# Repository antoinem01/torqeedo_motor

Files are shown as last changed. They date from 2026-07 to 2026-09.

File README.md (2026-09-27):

# Torqeedo motor

Arduino sketch that drives a Torqeedo motor over RS485, with a potentiometer for speed control and two safety switches (emergency stop and dead man switch).

## Documentation

- [Torqeedo 1103CL aansturing](docs/torqeedo-1103cl-aansturing.md)
- [Bench-test checklist](docs/bench-test-checklist.md)
- [IP68 & trillingsbestendige opbouw](docs/ip68-robuuste-opbouw.md)
- [Geïntegreerde PCB (alles op één print)](docs/pcb-geintegreerd.md)
- [KiCad-project: schema + printontwerp](hardware/kicad/README.md)

## Hardware

Components:

- Arduino Uno
- MAX485 TTL-RS485 module
- Potentiometer (speed control)
- Emergency stop button (normally closed)
- Dead man switch (normally open)
- Torqeedo Travel 1103 CL motor

Pins:

- `2` — RS485 TX (to MAX485 `DI`)
- `3` — RS485 RX (to MAX485 `RO`)
- `4` — RS485 DE (driver enable, to MAX485 `DE`+`RE`)
- `A0` — potentiometer wiper (speed control)
- `5` — emergency stop (normally closed button between pin and GND)
- `6` — dead man switch (normally open button between pin and GND)

### System diagram

Intended full setup, powered from the Torqeedo battery pack:

```mermaid
graph TD
    BAT["Torqeedo battery 29.6V<br/>(built-in BMS: overcharge/<br/>short-circuit/deep-discharge protection)"]
    SW["Main switch / pull-out plug"]
    FUSE1["Fuse ~40A<br/>(motor circuit)"]
    FUSE2["Fuse ~1A<br/>(logic circuit)"]
    MOTOR["Torqeedo Travel 1103 CL motor"]
    BUCK["DC-DC buck converter<br/>29.6V to 5-9V"]
    UNO["Arduino Uno"]
    TTL["MAX485 TTL-RS485 module"]
    POT["Potentiometer (A0)"]
    ESTOP["Emergency stop (pin 5)"]
    DMAN["Dead man switch (pin 6)"]

    BAT --> SW
    SW --> FUSE1 --> MOTOR
    SW --> FUSE2 --> BUCK --> UNO
    UNO -- "TX / RX / DE" --> TTL
    TTL -- "RS485 A/B twisted pair" --> MOTOR
    POT --> UNO
    ESTOP --> UNO
    DMAN --> UNO
    BAT -. "common ground" .- UNO
    BAT -. "common ground" .- TTL
```

Notes:

- Two **separate fuses**: a heavy one (~40A) for the motor circuit and a small one
  (~1A) for the logic circuit. A single shared fuse is risky — a motor current
  spike could take down the Arduino's power too.
- The Uno is powered from the same battery as the motor, via a DC-DC buck
  converter (29.6V → 5-9V), not from an independent power source.
- A main switch / pull-out plug in front of everything lets you fully de-energize
  the system, independent of the software emergency stop on pin 5.
- The battery, Uno and TTL module must share a **common ground** — easy to
  forget, but required for the RS485 signal reference to work reliably.

### RS485 wiring

A cheap MAX485 breakout module is used to convert the Arduino's UART signal to the
RS485 bus. On these modules DE and RE are usually tied together, so a single
Arduino pin can drive both:

| Arduino Uno | MAX485 module |
| --- | --- |
| `5V` | `VCC` |
| `GND` | `GND` |
| `2` (TX) | `DI` |
| `3` (RX) | `RO` |
| `4` (DE) | `DE` + `RE` (tied together) |
| — | `A` / `B` → to the Torqeedo RS485 bus |

Check the `A`/`B` polarity against the Torqeedo motor's connector documentation —
if the motor doesn't respond, try swapping `A` and `B`.

### Torqeedo model

Target motor: **Torqeedo Travel 1103 CL** (long-shaft).

**Status: validated against the real motor** (bench test, 2026-07-25). The sketch
was tested against an actual Travel 1103 CL powered from an adjustable DC supply
at 29 V, propeller in air (no load). The motor's controller drew ~0.06 A idle,
responded to throttle, and the propeller ran both **forward and reverse** as
commanded. The RS485 protocol (based on ArduPilot's `AP_Torqeedo`) works against
this model and firmware.

This validation was **no-load only**. The current bench rig is a breadboard
lash-up, not a robust install, and the on-water power topology (buck converter,
fuses, main switch) has not been built or tested yet. Keep testing carefully,
without load, before relying on it on the water.

### ⚠️ Safety

This sketch controls a real motor, potentially on a boat. Bugs, wiring mistakes,
or protocol misunderstandings can cause unexpected motor behavior. Always:

- Test on the bench, out of the water, with the propeller removed or the boat secured, before any on-water use.
- Verify the emergency stop and dead man switch actually cut power before trusting them.
- Use at your own risk — this project comes with **no warranty**, see [LICENSE](LICENSE).

## How it works

- Reads the potentiometer and drives the motor via an RS485 protocol with a CRC8 checksum.
- Speed is ramped up/down gradually (soft start/stop, max 10 units per 100 ms).
- The motor stops immediately on emergency stop or when the dead man switch is released.
- A watchdog timer (2 s) restarts the Arduino if the loop hangs.
- The number of errors/stops is tracked in EEPROM.

## Libraries

Only standard Arduino libraries are needed, no external dependencies:

- `SoftwareSerial`
- `EEPROM`
- `avr/wdt`

## Uploading

Open `Torqeedo_motor/Torqeedo_motor.ino` in the Arduino IDE (or use `arduino-cli`), select board **Arduino Uno**, and upload.

## Credits

The RS485 bus protocol (framing bytes `0xAC`/`0xAD`/`0xAE`, CRC8 checksum) is based on
[ArduPilot's `AP_Torqeedo` driver](https://github.com/ArduPilot/ardupilot/tree/master/libraries/AP_Torqeedo).
Many thanks to the ArduPilot project for documenting and implementing the Torqeedo bus protocol.

## License

GPLv3, see [LICENSE](LICENSE) — inherited from ArduPilot's GPLv3-licensed `AP_Torqeedo` driver, on which the protocol implementation is based.

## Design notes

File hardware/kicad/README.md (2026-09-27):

# KiCad-project — geïntegreerde besturingsprint

Schema **en** printontwerp voor de geïntegreerde besturingsprint uit
[`../../docs/pcb-geintegreerd.md`](../../docs/pcb-geintegreerd.md).

## Bestanden

| Bestand | Inhoud |
|---|---|
| `torqeedo_pcb.kicad_pro` | projectbestand — **open dit in KiCad** |
| `torqeedo_pcb.kicad_sch` | schema (netlist, footprints toegewezen) |
| `torqeedo_pcb.kicad_pcb` | **printontwerp: geplaatst, gerouteerd, massavlakken** |
| `fab/` | Gerbers + boorbestanden (`*-gerbers.zip`), BOM, plaatsingsbestand |
| `pcb-top.png` / `pcb-bottom.png` | 3D-weergave van boven- en onderkant |

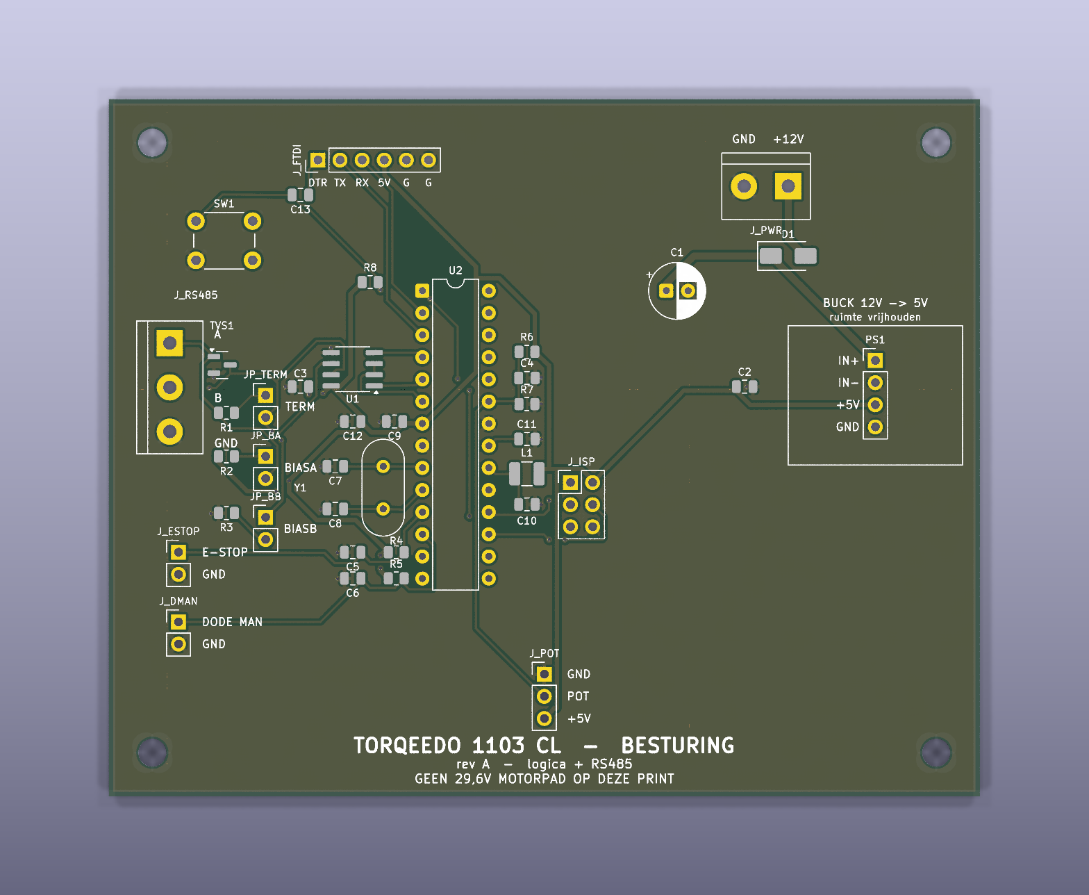
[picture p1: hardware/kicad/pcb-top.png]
Bovenkant


De symbolen zijn **in het schema ingebed**; de footprints komen uit de
**standaard KiCad-bibliotheken** (KiCad 9). Geen externe libraries nodig.

## De print

| | |
|---|---|
| Formaat | **100 × 80 mm**, 2 lagen, 1,6 mm |
| Montage | 4× **M3** (⌀3,2 mm) op 5 mm van elke hoek |
| Koperlagen | **F.Cu** = signalen, **B.Cu** = doorlopend **massavlak** (92,8 % dicht, één eiland) |
| Baanbreedtes | 0,25 mm signaal · 0,50 mm +5 V/GND · 0,80 mm +12 V |
| Via's | 0,7 mm pad / 0,35 mm boring — 32 stuks, waarvan 15 stitching-via's naar het massavlak |
| Clearance | 0,25 mm (netclasses `Default` / `Power` / `HV` staan in het projectbestand) |

De onderlaag is bewust bijna onaangeroerd gelaten: alleen een handvol korte
oversteekjes, zodat het massavlak een **aaneengesloten retourpad** blijft.

## Indeling

```
 ┌──────────────────────────────────────────────────────────┐
 │  SW1  C13   J_FTDI                          J_PWR  D1    │  ← 12 V in, ompoling
 │                                        C1        ┌─────┐ │
 │ J_RS485  TVS1  JP_*   U1      U2    R6/C4/R7  C2 │BUCK │ │  ← 12 V→5 V module
 │   A/B/G  R1-R3        MAX485  ATmega  C11        │PS1  │ │     (ruimte vrij)
 │                       C3      328P    L1/C10     └─────┘ │
 │                   C7 Y1 C8            J_ISP              │
 │ J_ESTOP    C5/C6  R4/R5                                  │
 │ J_DMAN                     J_POT                         │
 │            TORQEEDO 1103 CL - BESTURING  rev A           │
 └──────────────────────────────────────────────────────────┘
```

De plaatsing volgt de aandachtspunten uit
[`pcb-geintegreerd.md` §11](../../docs/pcb-geintegreerd.md):

- **Kristal Y1 staat pal tegen pin 9/10** van de ATmega — XTAL1 is 9,1 mm en
  XTAL2 10,0 mm lang, beide zonder via, met C7/C8 er direct naast.
- **Ontkoppeling tegen de voedingspinnen:** C9 bij VCC (pin 7), C3 bij MAX485
  pin 8, L1+C10 (AVCC-filter) direct bij pin 20, C11 bij AREF.
- **Analoge tak kort en ver van de buck:** C4/R6/R7 staan tegen pin 23; de
  A0-baan loopt op **40,9 mm** van de buck-module en 18,3 mm van het
  12 V-koper.
- **RS485 bij de connector:** terminatie (R1/JP_TERM), bias (R2/R3/JP_BA/JP_BB)
  en TVS1 staan tussen U1 en J_RS485; A en B lopen als paar.
- **Voedingsscheiding:** J_PWR, D1, C1 en de buck zitten samen in de
  rechterbovenhoek, gescheiden van de 5 V-logica en de A0-lijn.
- **Veldbedrading** (RS485, potmeter, noodstop, dode man) zit aan de linker- en
  onderrand; **programmeerheaders** (J_FTDI, J_ISP) liggen vrij bereikbaar.

Op de silkscreen staan de aansluitingen benoemd (`+12V`/`GND`, `A`/`B`/`GND`,
`POT`, `E-STOP`, `DODE MAN`, `IN+`/`IN-`/`+5V`/`GND`, `DTR TX RX 5V G G`), plus
het gereserveerde vlak voor de buck-module.

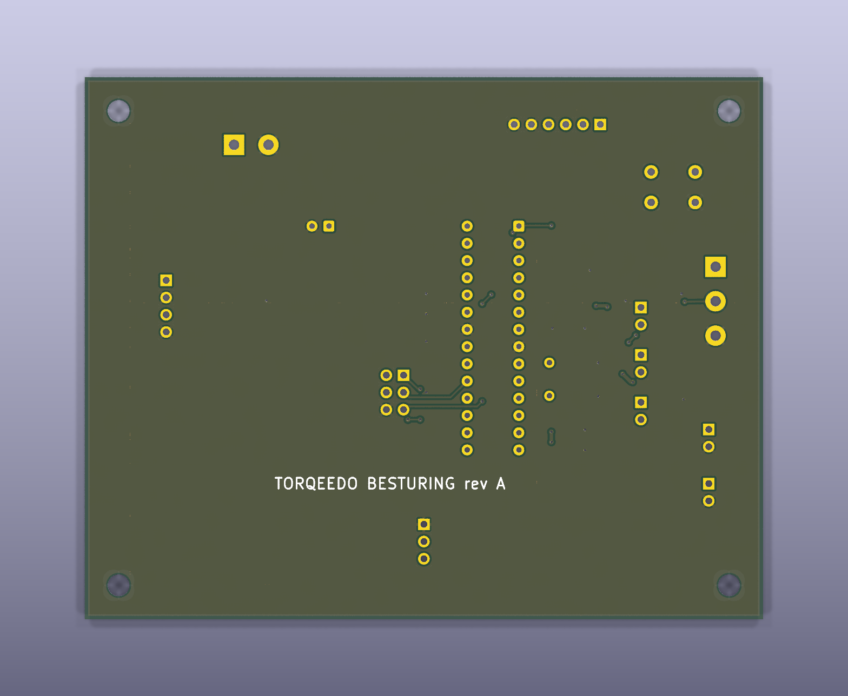
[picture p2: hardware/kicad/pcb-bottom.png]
Onderkant — doorlopend massavlak


## Verificatiestatus

Gecontroleerd met KiCad 9.0.2:

- **DRC: 0 overtredingen, 0 onverbonden items** (inclusief silkscreen- en
  afbakeningsregels).
- **Netlist print = netlist schema:** alle **114 pad-net-verbindingen** en 39
  componenten komen exact overeen; geen footprint-afwijkingen.
- Alle silkscreen-tekst valt binnen de bordrand.

> Dit is een **ontwerp-verificatie, geen gebouwde print.** Zie hieronder wat je
> vóór bestellen zelf moet nakijken.

## Nakijken vóór je bestelt

1. **PS1 buck-module** — de 1×4 header gaat uit van de padvolgorde
   **IN+ / IN− / OUT+ / OUT−**. Leg dit naast de pinout van *jouw* module en pas
   de footprint of de bedrading aan als die anders is. Het silkscreen-kader
   (20 × 16 mm) is de ruimte die de module krijgt — controleer of hij past.
2. **TVS1 SM712** — aangenomen SOT-23-pinout is pin 1 = A, 2 = GND, 3 = B.
   Controleer tegen het datasheet (optioneel onderdeel, dus laag risico).
3. **D1** — kathode (band) hoort aan de `+12V_PROT`-kant; zo is hij bedraad,
   controleer de silk-oriëntatie.
4. **C2/C12 (10 µF)** staan als keramisch 0805. Wil je elco's, wijs dan
   `CP_Radial` toe en let op polariteit.
5. **J_FTDI VCC** — laat los als de print al via de buck gevoed wordt
   (zie [`pcb-geintegreerd.md` §5](../../docs/pcb-geintegreerd.md)).

## Fabricagebestanden opnieuw maken

```sh
kicad-cli pcb export gerbers --no-protel-ext \
  --layers F.Cu,B.Cu,F.Mask,B.Mask,F.Silkscreen,B.Silkscreen,F.Paste,Edge.Cuts \
  -o fab/ torqeedo_pcb.kicad_pcb
kicad-cli pcb export drill --format excellon --excellon-separate-th -o fab/ torqeedo_pcb.kicad_pcb
kicad-cli pcb export pos --format csv --units mm --side both -o fab/torqeedo_pcb-pos.csv torqeedo_pcb.kicad_pcb
kicad-cli pcb drc --severity-error --severity-warning torqeedo_pcb.kicad_pcb
```

`fab/torqeedo_pcb-gerbers.zip` is wat je bij een fabrikant (JLCPCB, Aisler,
Eurocircuits) uploadt. Standaard 2-laags 1,6 mm proces; de kleinste maten op de
print (0,25 mm baan, 0,35 mm boring) zitten ruim binnen wat iedereen aankan.

## Bekende oneffenheid

De referenties `J_PWR`, `J_POT`, `JP_BA`, … eindigen niet op een cijfer. KiCad
ziet zulke namen als **niet-geannoteerd** en meldt dat bij het openen van het
schema; in de BOM verschijnen ze als `J_PWR?`. Dat is **cosmetisch** — netlist,
print en fabricagebestanden zijn correct (de print gebruikt de namen zonder
`?`). Wil je het weg hebben, hernoem dan in het schema naar bijvoorbeeld
`J_PWR1`; dan moeten de verwijzingen in `docs/pcb-geintegreerd.md` mee.

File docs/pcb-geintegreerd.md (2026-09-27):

# Geïntegreerde PCB (alles op één print)

Schema-ontwerp voor **één print waarop alles samenkomt**: een kale
**ATmega328P** (geen Arduino-module), de **MAX485**, de **12 V→5 V-voeding**,
de connectoren en de bus-beveiliging. Dezelfde sketch (`Torqeedo_motor.ino`)
draait ongewijzigd op de losse ATmega — de Nano is enkel vervangen door de chip
zelf plus een kristal, reset-circuit en een programmeer-header.

Een **KiCad-project** met zowel het schema als het **uitgewerkte printontwerp**
staat in [`../hardware/kicad/`](../hardware/kicad/) (open `torqeedo_pcb.kicad_pro`).
De print is 100 × 80 mm, 2-laags, volledig gerouteerd met een doorlopend
massavlak op de onderlaag, en DRC-schoon; `hardware/kicad/fab/` bevat de
Gerbers om hem te laten maken. De [hardware-README](../hardware/kicad/README.md)
beschrijft de indeling en wat je vóór bestellen nog moet nakijken.

Dit document geeft de **elektrische** kant (blokschema, connectielijst,
onderdelenlijst). De waterdichte/trillingsbestendige opbouw staat in
[`ip68-robuuste-opbouw.md`](ip68-robuuste-opbouw.md); de pinout en het protocol
in [`torqeedo-1103cl-aansturing.md`](torqeedo-1103cl-aansturing.md); de
voedingstopologie (accu, zekeringen, hoofdschakelaar) in de
[`README`](../README.md).

> ⚠️ Deze print is de **logica + RS485** ("brain"). Het **zware motorpad
> (~40 A, 29,6 V)** en de **40 A-zekering** horen er **niet** op — die lopen
> los langs de print, precies zoals de twee-zekeringen-opzet in de README.
> Op deze print komt alleen de **gelogde ~1 A tak** binnen.

---

## 1. Voeding: 12 V → 5 V

De print wordt gevoed met **12 V** en maakt daar met een buck **5,0 V** van.
Die 5 V voedt de ATmega, de MAX485, de potmeter en de pull-ups.

De 12 V komt van een **12 V-tak** — in de praktijk een 29,6 V→12 V-omvormer
bovenstrooms, of een aparte 12 V-accu aan boord. Alleen de gelogde ~1 A tak
(met de ~1 A-zekering uit de README) komt hier binnen; het 29,6 V motorpad
blijft er volledig van gescheiden.

**Buck als module op de print (aanbevolen).** Monteer een kant-en-klare
12 V→5 V buck-module op headers/pads op dezelfde print. Het blijft één PCB waar
alles samenkomt, maar je vermijdt het lastigste stuk voor een eerste eigen
ontwerp: de layout van een schakelende regelaar (inductor, feedback, ground
return). *Optie:* volledig integreren met een buck-IC (MP2307/MP1584/LM2596 +
inductor + dioden/caps) als je vertrouwd bent met switching-layout.

```mermaid
graph LR
    subgraph OFFBOARD["Buiten de print"]
        FUSE["Zekering ~1A"]
        POT["Potmeter 10k"]
        ESTOP["Noodstop (NC)"]
        DMAN["Dode man (NO)"]
        MOTOR["Torqeedo RS485-bus"]
    end

    subgraph PCB["Geïntegreerde PCB"]
        D1["D1 Schottky<br/>ompoolbeveiliging"]
        BUCK["Buck 12V → 5,0V"]
        MCU["ATmega328P<br/>+ 16MHz kristal<br/>+ reset + ISP/FTDI"]
        MAX["MAX485 (SO-8)<br/>+ terminatie/bias/TVS"]
    end

    FUSE -->|+12V| D1 --> BUCK -->|"+5V"| MCU
    MCU -->|"PD2/PD3/PD4"| MAX
    MCU -->|"+5V"| MAX
    POT -->|PC0/A0| MCU
    ESTOP -->|PD5/D5| MCU
    DMAN -->|PD6/D6| MCU
    MAX -->|"A / B / GND"| MOTOR
```

---

## 2. ATmega328P (U2) — kern

De kale chip vervangt de Nano. Voor betrouwbare SoftwareSerial (19200 baud) is
een **extern 16 MHz-kristal** nodig; de interne 8 MHz-RC-oscillator is te
onnauwkeurig voor stabiele seriële timing. Draai de **Arduino Uno-bootloader**
en dezelfde sketch — de code is 1-op-1 overdraagbaar.

Benodigd rond de chip:

- **Y1 16 MHz-kristal** + **C7/C8 (22 pF)** naar GND, vlak bij XTAL1/XTAL2
  (pin 9/10).
- **Reset:** R8 (10 kΩ) van RESET (pin 1) naar +5 V; optionele reset-knop naar
  GND; C13 (100 nF) van de FTDI-DTR-lijn naar RESET voor auto-reset bij uploaden.
- **Ontkoppeling:** C9 (100 nF) bij VCC (pin 7), C12 (10 µF) bulk vlakbij.
- **Schone ADC-voeding** (belangrijk voor een stabiele pot-meting): **L1
  (10 µH of ferriet)** tussen +5 V en **AVCC (pin 20)**, met **C10 (100 nF)**
  van AVCC naar AGND. **AREF (pin 21)** via **C11 (100 nF)** naar GND (interne
  AVcc-referentie; géén externe ref aansluiten). **AGND (pin 22)** naar GND.
- **J_ISP (2×3):** bootloader branden / direct programmeren (MISO/MOSI/SCK/
  RESET/VCC/GND).
- **J_FTDI (1×6):** uploaden en Serial-debug via een externe USB-serial-adapter
  (§5).

---

## 3. Pintoewijzing (sketch → fysieke ATmega-pin)

De Arduino-pinnamen uit `Torqeedo_motor.ino` mappen zo op de DIP-28/TQFP-32:

| Sketch | Arduino | ATmega-pin (DIP-28) | Poort | Gaat naar |
|---|---|---|---|---|
| `RS485_TX` | D2 | 4 | PD2 | MAX485 **DI** (pin 4) |
| `RS485_RX` | D3 | 5 | PD3 | MAX485 **RO** (pin 1) |
| `RS485_DE` | D4 | 6 | PD4 | MAX485 **DE**+**RE** (pin 3+2) |
| `POT_PIN` | A0 | 23 | PC0 | potmeter-loper (§7) |
| `NOODSTOP_PIN` | D5 | 11 | PD5 | noodstop (§8) |
| `DODE_MAN_PIN` | D6 | 12 | PD6 | dode man (§8) |
| Serial TX | D1 | 3 | PD1 | J_FTDI RXI (debug/upload) |
| Serial RX | D0 | 2 | PD0 | J_FTDI TXO (debug/upload) |

Voeding/klok/reset: VCC pin 7, GND pin 8, AVCC pin 20, AGND pin 22, AREF pin 21,
XTAL1/2 pin 9/10, RESET pin 1.

---

## 4. MAX485 (U1, SO-8)

Standaard MAX485-pinout. **DE en RE aan elkaar** en samen naar `D4` (PD4), zodat
één pin zenden/ontvangen omschakelt.

| MAX485-pin | Naam | Verbinding |
|---|---|---|
| 1 | RO | ATmega PD3 (pin 5) |
| 2 | RE̅ | samen met pin 3 → ATmega PD4 (pin 6) |
| 3 | DE | samen met pin 2 → ATmega PD4 (pin 6) |
| 4 | DI | ATmega PD2 (pin 4) |
| 5 | GND | GND |
| 6 | A | bus **A** → J_RS485 |
| 7 | B | bus **B** → J_RS485 |
| 8 | VCC | +5 V (100 nF ontkoppeling naar GND, dicht bij pin 8) |

---

## 5. Programmeren & debug (J_FTDI, 1×6)

Brand eenmalig de bootloader via **J_ISP** (met een USBasp/Arduino-as-ISP).
Daarna upload je net als een Arduino Pro Mini via een **USB-serial-adapter** op
J_FTDI, en dient dezelfde header voor de Serial-debugregels uit de sketch.

| J_FTDI-pin | Functie | Verbinding |
|---|---|---|
| DTR | auto-reset | via C13 (100 nF) → RESET (pin 1) |
| RXI | adapter **ontvangt** | → ATmega **TX** = PD1 (pin 3) |
| TXO | adapter **zendt** | → ATmega **RX** = PD0 (pin 2) |
| VCC | 5 V | zie noot |
| CTS | — | GND |
| GND | massa | GND |

> **RX/TX kruisen:** de adapter-RX gaat naar de chip-TX en andersom — de klassieke
> valkuil. **VCC-noot:** laat J_FTDI VCC **los** als de print al door de buck
> (12 V) gevoed wordt, om twee bronnen op +5 V te vermijden. Voor kaal
> bench-programmeren zonder 12 V mag je juist wél via J_FTDI VCC voeden.

---

## 6. Connectielijst (netlist)

Per net; dit is wat je in KiCad/EasyEDA aan elkaar trekt. Referenties: §9.

**GND** (sterpunt / massavlak)
: J_PWR.2 · C1− · buck IN− · buck OUT− · U2.8 · U2.22(AGND) · U1.5 · J_POT.1 ·
  J_ESTOP.2 · J_DMAN.2 · J_RS485.3 · C2− · C3 · C4 · C5 · C6 · C7 · C8 · C9 ·
  C10 · C11 · C12− · R3 · R7 · J_ISP.GND · J_FTDI.GND · J_FTDI.CTS · TVS-massa

**+12V_IN** (van de ~1 A-zekering): J_PWR.1 · D1 anode
**+12V_PROT** (na ompoolbeveiliging): D1 kathode · C1+ · buck IN+

**+5V** (buck-uitgang → voedt alles)
: buck OUT+ · U2.7(VCC) · U1.8 · C2+ · C9 · C12+ · L1 (→AVCC) · R8 (→RESET) ·
  J_POT.3 · R2 (bias→A) · R4 (pull-up D5) · R5 (pull-up D6) · R6 (fail-safe→A0) ·
  J_ISP.VCC

**AVCC**: U2.20 · L1 (van +5V) · C10 (→AGND)
**AREF**: U2.21 · C11 (→GND)
**XTAL1**: U2.9 · Y1 · C7 (→GND)
**XTAL2**: U2.10 · Y1 · C8 (→GND)
**RESET**: U2.1 · R8 (→+5V) · C13 (→J_FTDI.DTR) · SW_rst (→GND) · J_ISP.RST

**RS485_DI**: U2.4 (PD2) · U1.4
**RS485_RO**: U2.5 (PD3) · U1.1
**RS485_DE**: U2.6 (PD4) · U1.2 · U1.3

**BUS_A**: U1.6 · J_RS485.1 · R1 (via JP_TERM) · R2 (bias) · TVS-A
**BUS_B**: U1.7 · J_RS485.2 · R1 (via JP_TERM) · R3 (bias→GND) · TVS-B

**POT_A0**: U2.23 (PC0) · J_POT.2 · C4 (100 nF→GND) · R6 (100k→+5V) · R7 (100k→GND)

**ESTOP_D5**: U2.11 (PD5) · J_ESTOP.1 · R4 (10k→+5V) · C5 (100 nF→GND)
**DMAN_D6**: U2.12 (PD6) · J_DMAN.1 · R5 (10k→+5V) · C6 (100 nF→GND)

**UART_TX**: U2.3 (PD1) · J_FTDI.RXI
**UART_RX**: U2.2 (PD0) · J_FTDI.TXO

**ISP**: J_ISP.MOSI→U2.17(PB3) · J_ISP.MISO→U2.18(PB4) · J_ISP.SCK→U2.19(PB5) ·
  J_ISP.RST→RESET-net

---

## 7. Ontwerpkeuzes & opties

**Buck (12 V → 5,0 V).** Module met ruime marge (≥1 A, liefst 2-3 A) zodat hij
koel blijft. Stel de uitgang op **5,0 V** en **meet/fixeer** die vóór je de
ATmega voedt.

**Ompoolbeveiliging (D1).** Serie-Schottky (SS34, 40 V/3 A) op de 12 V-ingang;
~0,4 V verlies is verwaarloosbaar. Minder verlies? High-side P-MOSFET.

**RS485-terminatie (R1, 120 Ω) via JP_TERM.** Alleen aan de **uiteinden** van de
bus dichtzetten.

**Failsafe-bias (R2/R3, 560 Ω) via JP_BIAS — optioneel.** Gedefinieerde idle-bus;
op één plek op de bus plaatsen.

**TVS-beveiliging (SM712) — optioneel, aanbevolen voor de boot.** Vangt
spikes/ESD op de lange kabel; vervangt R2/R3 niet.

**ATmega-behuizing.** **DIP-28 in een voetje** is het makkelijkst voor een
eerste print: handmatig soldeerbaar en vervangbaar. TQFP-32 (SMD) is compacter
maar vergt fijner soldeerwerk.

---

## 8. Onderdelenlijst (BOM)

| Ref | Waarde / type | Opmerking |
|---|---|---|
| U2 | ATmega328P-PU (DIP-28) | in voetje; Uno-bootloader + sketch |
| U1 | MAX485 (SO-8) | 5 V RS485-transceiver, DE+RE-type |
| — | Buck-module 12 V→5 V, ≥1 A | op headers/pads, ingesteld op 5,0 V |
| Y1 | 16 MHz kristal | klok voor stabiele SoftwareSerial |
| D1 | Schottky SS34 (40 V/3 A) | ompoolbeveiliging 12 V-ingang |
| L1 | 10 µH inductor of ferriet | AVCC-filter (schone ADC) |
| C1 | 100 µF / 25 V elco | bulk buck-ingang (12 V) |
| C2 | 10 µF / 16 V | +5 V bulk |
| C3 | 100 nF | ontkoppeling MAX485 |
| C4 | 100 nF | filter op A0 |
| C5, C6 | 100 nF | ontdendering noodstop / dode man |
| C7, C8 | 22 pF | kristal-belastingscaps |
| C9 | 100 nF | ontkoppeling VCC (pin 7) |
| C10 | 100 nF | ontkoppeling AVCC (pin 20) |
| C11 | 100 nF | AREF (pin 21) |
| C12 | 10 µF | bulk bij MCU |
| C13 | 100 nF | auto-reset (DTR→RESET) |
| R1 | 120 Ω | bus-terminatie (via JP_TERM) |
| R2, R3 | 560 Ω | failsafe-bias (optioneel) |
| R4, R5 | 10 kΩ | pull-up D5 / D6 (optioneel) |
| R6, R7 | 100 kΩ | fail-safe-divider op A0 (§7 → nu §10) |
| R8 | 10 kΩ | RESET pull-up |
| SW_rst | drukknop | reset (optioneel) |
| TVS1 | SM712 | RS485-bus-beveiliging (optioneel) |
| K1 | relais of driver-header | hardware-cutoff motorpad (optioneel) |
| JP_TERM | 2-pin header + jumper | terminatie aan/uit |
| JP_BIAS | 2×2 header + jumpers | bias aan/uit (optioneel) |
| J_ISP | 2×3 header | bootloader / programmeren |
| J_FTDI | 1×6 header | upload + Serial-debug |
| J_PWR | 2-pin schroefklem 5,08 mm | +12 V (na zekering) + GND |
| J_RS485 | 3-pin schroefklem | bus A / B / GND naar motor |
| J_POT | 3-pin (JST-XH of schroef) | 5 V / loper / GND |
| J_ESTOP | 2-pin | noodstop (NC) |
| J_DMAN | 2-pin | dode man (NO) |

Alle connectoren bij voorkeur met vergrendeling of schroefklem — zie
[`ip68`](ip68-robuuste-opbouw.md) §4/§5.

---

## 9. Potmeter

De potmeter zet de sketch om in snelheid: links = vol achteruit, midden = stop,
rechts = vol vooruit, met een dode zone rond het midden
(`abs(doelSnelheid) < 50 → 0`).

- **Type:** 10 kΩ **lineair**. Lage baanstroom en lage bronimpedantie voor de ADC.
- **Bediening met midden-detent:** kies een uitvoering (of marine gashendel) met
  een **voelbaar middenstand-klikje** zodat "stop" op de tast te vinden is.
  Waterdicht/contactloos alternatief: **AS5600 hall-sensor** —
  [`ip68`](ip68-robuuste-opbouw.md) §7.
- **Bedrading (J_POT, 3-polig):** pin 3 = **+5 V**, pin 2 = **loper → A0** (PC0),
  pin 1 = **GND**. Draai +5 V/GND om als links/rechts omgekeerd is.
- **Ruisfilter (C4, 100 nF op A0→GND):** onderdrukt inductie op de lange kabel.

**Fail-safe bij draadbreuk (R6/R7, 2× 100 kΩ) — sterk aanbevolen.**
Breekt de **loper-draad** (of raakt de stekker los), dan zweeft `A0` en zou de
motor een willekeurige snelheid kunnen krijgen. Eén 100 kΩ van `A0` naar **+5 V**
en één naar **GND** trekken een zwevende `A0` naar **2,5 V = midden = stop**
(valt in de dode zone). Bij een aangesloten loper domineert de lage
potmeter-impedantie, dus de meetwaarde verschuift ~1 % — ruim binnen de dode
zone. **Geen** aanpassing in de sketch nodig.

---

## 10. Noodstop & dode man

De sketch leest beide schakelaars als pin-naar-GND en stopt de motor bij noodstop
of losgelaten dode man. Dat is de **software-laag** en al gevalideerd. Voor een
boot loont een **tweede, software-onafhankelijke laag**.

**Laag 1 — software (op deze print, zoals gecodeerd).**

- **Noodstop:** NC-drukknop tussen `J_ESTOP.1` en GND. Ingedrukt = open →
  `D5` (PD5) HIGH → stop. Gebroken draad = óók HIGH → faalt veilig.
- **Dode man:** NO-knop tussen `J_DMAN.1` en GND. Vasthouden = LOW = draaien;
  loslaten of gebroken draad = HIGH → stop.
- **Op de print:** pull-up (R4/R5) + 100 nF (C5/C6) voor ruisimmuniteit.
- Deze laag geeft **soft-stop**, **EEPROM-logging** en de
  **comms-loss-failsafe** — dingen die een mechanische onderbreking niet doet.

**Laag 2 — onafhankelijke hardware-cutoff (aanbevolen).**
Een defecte ATmega of vastgelopen firmware mag de motor niet kunnen laten
doordraaien. Onderbreek daarom **de motorvoeding/enable fysiek**, buiten de
software om:

- Gebruik schakelaars met **twee contacten** (DPST/DPDT-noodstop, dode man met
  hulpcontact). **Pool 1** → print (`D5`/`D6`, laag 1). **Pool 2** → een
  **veiligheidsketen**.
- **Veiligheidsketen (in serie):** `+12 V → noodstop (NC) → dode man (NO,
  ingedrukt) → spoel van contactor/relais K → GND`. Alles intact én dode man
  vastgehouden = spoel bekrachtigd = **motorvoeding/enable** door. Eén los →
  keten open → spoel valt af → **motorpad onderbroken**, ongeacht de ATmega.
- De contactor zit in het **29,6 V motorpad** (off-board, bij de 40 A-zekering).
  Deze print draagt alleen de laagvermogen-keten of een driver-header (K1).

> **Waarom de logica bewust blijft leven:** je onderbreekt het **motorpad**, niet
> de 12 V/5 V-voeding van de ATmega. De controller blijft draaien om netjes
> `stuurSnelheid(0)` te sturen en te loggen, terwijl de hardware-keten
> onafhankelijk garandeert dat er geen vermogen naar de motor gaat.

---

## 11. Layout-aandachtspunten

> Deze punten zijn **verwerkt** in `hardware/kicad/torqeedo_pcb.kicad_pcb`; de
> [hardware-README](../hardware/kicad/README.md) laat per punt zien hoe.

- **Massavlak** op de onderlaag; alle GND-punten sterpunt-achtig daaraan.
- **Kristal (Y1, C7/C8)** zo dicht mogelijk bij pin 9/10, korte banen, GND-guard.
- **AVCC-filter (L1/C10)** vlak bij pin 20; analoge GND (pin 22) apart naar het
  sterpunt houden voor een schone ADC.
- **Scheid de 12 V-ingang** (J_PWR, D1, C1, buck) van de 5 V-logica en de A0-lijn.
- **A/B als paar** routeren; terminatie/bias/TVS vlak bij J_RS485.
- **C3/C9/C10** direct tegen de betreffende voedingspinnen.
- **A0-baan kort** en weg van de buck; C4/R6/R7 vlak bij pin 23.
- **Buck vrij** houden voor koeling.
- **Montagegaten** (M3) passend bij de behuizing/standoffs uit
  [`ip68`](ip68-robuuste-opbouw.md).

---

## 12. Verificatie na assemblage

1. **Buck meten (5,0 V)** en op ompoling testen (D1 moet blokkeren) — vóór de
   ATmega spanning krijgt.
2. **Bootloader branden** via J_ISP; daarna de sketch uploaden via J_FTDI.
3. **Klok/serial check:** verschijnen de `Serial`-regels leesbaar op 9600 baud?
   Zo niet → kristal/22 pF nakijken.
4. [Bench-test checklist](bench-test-checklist.md) doorlopen — de print moet zich
   exact als het gevalideerde breadboard gedragen: pot stuurt, noodstop en dode
   man stoppen, `Motor comms OK` bij bus-antwoord.
5. **Potmeter-fail-safe:** trek de loper-draad los tijdens draaien → moet naar
   **stop** (midden) gaan.
6. **Hardware-cutoff** (als gebouwd): noodstop in / dode man los → het
   **motorpad** moet fysiek wegvallen, ook met de ATmega-voeding intact.

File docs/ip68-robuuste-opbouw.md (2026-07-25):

# IP68 & trillingsbestendige opbouw

Hoe je de aansturing van een **breadboard-prototype** naar een **waterdicht
(IP68)** en **schok-/trillingsbestendig** geheel brengt, geschikt voor permanent
gebruik op een boot. Dit document beschrijft de mechanische en afdichtings-kant;
de elektrische bedrading staat in [`torqeedo-1103cl-aansturing.md`](torqeedo-1103cl-aansturing.md)
en de voedingsopbouw (buck, zekeringen, hoofdschakelaar) in de
[`README`](../README.md).

> ⚠️ Het breadboard uit de banktest is **niet** geschikt voor gebruik op het
> water: trillingen schudden de steekverbindingen los en het is niet
> waterdicht. Alles hieronder gaat ervan uit dat je opnieuw en definitief
> opbouwt.

---

## 1. Wat betekent IP68 hier — en heb je het echt nodig?

| Code | Stof | Water |
|---|---|---|
| IP67 | Stofdicht | Onderdompeling tot **1 m / 30 min** |
| IP68 | Stofdicht | Langdurige onderdompeling, **dieper dan 1 m**, duur/diepte door fabrikant gespecificeerd |

Voor elektronica die **boven de waterlijn** in een kastje zit, is **IP67 in de
praktijk al ruim voldoende** (spatwater, regen, een golf). **IP68** is pas echt
nodig als het geheel **onder water** kan komen te staan of blijvend nat staat
(bilge, of montage laag in de romp). Kies bewust: IP68 is duurder en moeilijker
te onderhouden. De rest van dit document mikt op IP68, met IP67 als het
minimum-alternatief waar dat volstaat.

---

## 2. Twee strategieën

Er zijn twee manieren om IP68 + trillingsbestendig te halen. Ze sluiten elkaar
niet uit — je kunt een afgedichte behuizing combineren met lokaal ingieten.

| | A. Afgedichte behuizing | B. Volledig ingegoten (potting) |
|---|---|---|
| **Waterdicht** | Goed (afhankelijk van afdichting/wartels) | Uitstekend — hars sluit alles in |
| **Trillingsbestendig** | Redelijk (mits alles vastgezet) | Uitstekend — niets kan bewegen |
| **Warmteafvoer** | Goed (lucht rond componenten) | Slecht — hars houdt warmte vast |
| **Onderhoud/servicebaar** | Ja, kastje open | Nee — onherstelbaar ingegoten |
| **Aanpasbaar** | Ja | Nee |

**Aanbeveling:** begin met **A** (afgedichte behuizing met alles mechanisch
vastgezet). Dat geeft IP67–IP68 én blijft servicebaar. Overweeg **B (potting)**
alleen voor het kleine, definitieve print-deel als trillingen daar een
hardnekkig probleem blijven — en **giet de buck-converter nooit volledig in**
(warmte).

---

## 3. Behuizing

- **Rating:** IP68 (of IP67) afdichtdoos. Let op de fabrikantsopgave van
  diepte/duur bij IP68.
- **Materiaal:** ABS/polycarbonaat (goedkoop, corrosievrij) of aluminium
  (robuuster, betere warmteafvoer, maar let op galvanische corrosie in zilte
  omgeving — isoleer van andere metalen).
- **Formaat:** ruim kiezen — minimaal ~15×10×6 cm (Arduino Uno is 68×53 mm),
  plus ruimte voor MAX485, buck-converter, zekeringhouders en bedrading.
- **Deksel:** doorlopende siliconen/EPDM-afdichtring, roestvrije (RVS A4/316)
  schroeven. Draai kruislings en gelijkmatig aan zodat de ring egaal knijpt.
- **Montage van het kastje zelf:** op **trillingsdempers** (rubberen
  silentblocks) tegen de romp, niet star vastgeschroefd — dat scheelt de
  elektronica veel schok.

---

## 4. Elektronica trillingsbestendig monteren (weg van breadboard)

Dit is de kern van "tegen abrupte bewegingen". Trillingen en schokken breken
steekverbindingen, laten soldeer scheuren bij zware componenten en trekken
connectoren los.

- **Soldeer alles vast** op een perfboard/prototypeshield of een custom PCB —
  **geen breadboard, geen losse Dupont-draadjes** in de eindopstelling.
- **Zware componenten extra fixeren:** elco's, connectoren, de buck-converter en
  het MAX485-bordje vastzetten met een klodder **RTV-silicone of hot-glue** zodat
  ze niet op hun pootjes staan te trillen (dat vermoeit de soldeerpunten).
- **Print zwevend monteren** op RVS-afstandsbusjes met rubberen ringetjes of
  nylon standoffs — demp de print van de behuizing.
- **Connectoren met vergrendeling** waar losneembaar moet zijn: JST-XH met
  vergrendeling, of schroefklemmen (Phoenix-type). Vermijd gladde headerpinnen.
- **Schroefdraad borgen:** een druppel **schroefborgmiddel (Loctite)** of
  borgmoeren op bevestigingen die door trilling los kunnen lopen.
- **Trekontlasting op elke kabel** die de print of het kastje verlaat, zodat een
  ruk of trilling nooit op de soldeerpunt of de wartel komt.
- **Conformal coating** (acryl of urethaan) op de gesoldeerde print beschermt
  tegen vocht en condens — een goedkope, effectieve extra laag, ook zonder
  volledige potting.

---

## 5. Kabeldoorvoeren & connectoren

De afdichting is zo goed als zijn zwakste doorvoer. Standaard PG-wartels zijn
vaak maar IP54–IP68 afhankelijk van uitvoering — kies bewust.

- **Kabelwartels:** IP68-gecertificeerde wartels (M-serie, bijv. M12/M16/M20)
  met correcte klembereik voor de kabeldiameter. Te dun t.o.v. de wartel = geen
  afdichting. Gebruik een **blindstop** in ongebruikte gaten.
- **Externe connectoren (loskoppelbaar):** IP68 **M12-connectoren** of marine
  bulkhead-connectoren voor motorkabel, voeding en bediening. Handiger dan de
  kabel door een wartel als je onderdelen wilt kunnen loskoppelen.
- **Aantal doorvoeren** (minimaliseer — elke doorvoer is een risico):

  | Doorvoer | Voor |
  |---|---|
  | 1× | Motorkabel (RS485 A/B + GND, en evt. motorvoeding-retour) |
  | 1× | Voedingskabel van accu |
  | 1× | Bedieningskabel (potmeter/gashendel) |
  | 1× | Noodstop + dode man |

- **Afdichting rond de kabel** binnenin extra borgen met een kabelbinder/klem
  net binnen de wartel, zodat trek niet aan de afdichting trekt.

---

## 6. Condens & drukvereffening

Een volledig dichte behuizing "ademt" bij temperatuurwisselingen: opwarmen en
afkoelen bouwt onder-/overdruk op die de afdichting belast en vocht naar binnen
kan trekken. Condens binnenin is een sluipende oorzaak van corrosie.

- **Drukvereffeningsventiel (Gore-type breather):** laat lucht/druk door maar
  houdt water tegen (IP68). Sterk aanbevolen voor een dichte behuizing buiten.
- **Droogmiddel (silicagel)** zakje in het kastje als extra buffer tegen
  restvocht bij het sluiten.
- Sluit het kastje bij voorkeur in een **droge, koele omgeving** zodat je geen
  vochtige lucht opsluit.

---

## 7. Bediening & schakelaars

De bediening en veiligheidsschakelaars moeten dezelfde IP-klasse halen als de
rest — zij zitten buiten het kastje en krijgen direct water.

- **Bediening:** IP67/IP68 potmeter, of een **marine gashendel** (professioneel,
  goede haptiek, midden-detent voor voel-baar "stop"). Alternatief zonder
  mechanisch contact: **AS5600 hall-sensor** achter een afgedicht magneetknopje —
  onverwoestbaar en makkelijk waterdicht te maken.
- **Noodstop:** afgedichte (IP67+) paddenstoel-noodstop, normaal gesloten.
- **Dode man:** afgedichte drukknop of hendel, normaal open. Denk aan een
  marine-uitvoering die tegen zout en UV kan.
- **Kabels naar deze onderdelen** via IP68-wartels of M12-connectoren, met
  trekontlasting.

---

## 8. Kabels, routing & corrosie

- **Marine-grade kabel:** vertind koper (tinned copper) tegen corrosie, flexibel,
  met olie-/UV-bestendige mantel.
- **Routing vastzetten:** P-clips of kabelklemmen om de ~20–30 cm zodat kabels
  niet vrij hangen te zwiepen (trilling = draadbreuk bij de connector). Laat een
  kleine **serviceslinger** (lus) bij connectoren zodat er geen trek op staat.
- **Bevestigingsmateriaal:** RVS **A4/316** in zilte omgeving. Vermijd
  verschillende metalen tegen elkaar (galvanische corrosie).
- **Zekeringhouders & klemmen** in een waterdichte uitvoering of binnen het
  afgedichte kastje houden.

---

## 9. Warmte

Waterdicht maken en warmte afvoeren zijn tegengesteld. Het grootste warmtepunt
is de **buck-converter** (29,6 V → 5 V).

- Kies een buck met **ruime marge** op de stroom zodat hij koel blijft.
- **Giet de buck niet volledig in** hars (strategie B) — dan kan de warmte
  nergens heen.
- Bij een aluminium behuizing: monteer warme componenten **thermisch tegen de
  wand** (met thermisch pad) zodat de behuizing als koellichaam werkt.
- Houd de motor-vermogenselektronica (~40 A circuit) zo mogelijk **buiten** het
  logica-kastje — dat scheelt warmte en ruis.

---

## 10. Testprotocol

Test in deze volgorde, vóór montage op de boot:

1. **Droge functietest** — doorloop eerst de
   [bench-test checklist](bench-test-checklist.md) met de definitieve, gesoldeerde
   opbouw (nog niet dichtgemaakt). Alles moet werken zoals op het breadboard.
2. **Trillingstest** — schud/klop het kastje stevig, tik erop, terwijl de
   Serial Monitor of de motor loopt. Er mag **geen** onderbreking, reset of
   `STOP: comms lost` optreden. Zo niet → een verbinding zit los.
3. **Waterdichtheidstest (leeg of met dummy):** dompel de gesloten, afgedichte
   behuizing onder (of besproei ruim, afhankelijk van je doel-IP) en controleer
   op binnendringend water. Doe dit **vóór** je de echte elektronica erin
   vertrouwt — of test met een papieren indicator/silicagel die verkleurt.
4. **Thermische test** — laat het geheel een tijd draaien en voel/meet of niets
   oververhit (buck, MAX485, bedrading).
5. **Herhaal na trilling:** na de trillingstest nog eens de waterdichtheid
   controleren — trillingen kunnen een afdichting of wartel loswerken.

---

## 11. Onderdelen & zoektermen

| Onderdeel | Zoekterm |
|---|---|
| IP68 behuizing | "IP68 enclosure ABS", "waterproof enclosure" (Kiwi Electronics, Conrad, Reichelt) |
| IP68 kabelwartels | "IP68 cable gland M12/M16" |
| M12 connectoren | "M12 connector waterproof A-coded panel mount" |
| Drukvereffeningsventiel | "Gore protective vent", "pressure equalization valve M12" |
| Trillingsdempers | "rubber vibration mount / silentblock M4" |
| Conformal coating | "conformal coating acrylic PCB" (spuitbus) |
| Potting compound | "polyurethane potting compound" (flexibel, i.p.v. hard epoxy voor trillingen) |
| RVS bevestiging | "RVS A4 / 316 bouten moeren" |
| IP67 potmeter | "IP67 potentiometer waterproof" |
| Marine gashendel | "marine throttle control single lever" |
| Afgedichte noodstop | "IP67 emergency stop mushroom NC" |
| Vertind kabel | "marine tinned copper wire" |

---

## 12. Checklist

- [ ] Alles gesoldeerd op perfboard/PCB — **geen breadboard/Dupont** meer
- [ ] Zware componenten vastgezet met RTV/hot-glue
- [ ] Print op trillingsdempers/standoffs, kastje op silentblocks
- [ ] Conformal coating op de print
- [ ] Alle interne connectoren met vergrendeling; schroeven geborgd (Loctite)
- [ ] Trekontlasting op elke kabel
- [ ] IP68-wartels/M12-connectoren, ongebruikte gaten met blindstop
- [ ] Drukvereffeningsventiel + silicagel geplaatst
- [ ] Bediening + noodstop + dode man in IP67/IP68-uitvoering
- [ ] Kabels vastgeklemd (P-clips), serviceslinger bij connectoren
- [ ] RVS A4/316 bevestiging, geen ongelijke metalen tegen elkaar
- [ ] Buck-converter koel en **niet** ingegoten
- [ ] Trillingstest doorstaan zonder onderbreking/`STOP: comms lost`
- [ ] Waterdichtheidstest doorstaan (ook ná trillingstest)

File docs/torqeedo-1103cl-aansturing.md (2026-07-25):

# Torqeedo 1103CL — Arduino aansturing via RS485

## Doel

Potmeter → Arduino → RS485 → Torqeedo 1103CL (Long shaft, 24V)

---

## Hardware

| Onderdeel | Details |
|---|---|
| Motor | Torqeedo 1103CL (24V nominaal, tot ~29V vol) |
| Controller | Arduino (Uno/Nano) |
| RS485 interface | TTL-to-RS485 bordje (bijv. MAX485) |
| Bediening | Potmeter op A0 |
| Noodstop | Normaal gesloten drukknop op pin 5 |
| Dode man schakelaar | Normaal open drukknop op pin 6 |
| Voeding motor | 24V LiFePO4 accu (later: 48V accu via Victron Orion DC-DC) |
| Voeding Arduino | 5V via USB of eigen voeding |

---

## Aansluiting

### Potmeter → Arduino

De potmeter heeft 3 pinnen:

```
   +-----+
   |     |
   1  2  3
```

| Pin | Naam | Arduino |
|---|---|---|
| 1 | Linker buitenste | GND |
| 2 | Middelste (wiper) | A0 |
| 3 | Rechter buitenste | 5V |

Pin 1 en 3 mogen omgedraaid — dat bepaalt alleen welke kant vooruit is.

**Bediening (midden = stop):** de potmeterstand wordt gemapt op `-1000…+1000`.
Helemaal naar één kant = vol achteruit, midden = stil, helemaal naar de andere
kant = vol vooruit. Rond het midden zit een dode zone (~5%) zodat de motor bij
neutraal niet kruipt. Een draaipotmeter heeft geen mechanische midden-klik, dus
voor achteruit is een midden-detent potmeter of joystick/gashendel prettiger —
dan voel je waar stop zit.

### Arduino → RS485-bordje

Het TTL-to-RS485 bordje heeft aan de TTL-kant 4 pinnen (VCC, GND, RX, TX).
VCC = de positieve voedingspin (5V).

| TTL-bordje | Arduino |
|---|---|
| VCC | 5V |
| GND | GND |
| RX | Pin 3 (TX) |
| TX | Pin 2 (RX) |

Let op: RX van het bordje gaat naar TX van de Arduino en omgekeerd.

**Voeding delen zonder breadboard:** sluit een kort draadje van VCC op het RS485-bordje naar pin 3 van de potmeter, en van GND naar pin 1 van de potmeter.

De RS485-kant van het bordje heeft A en B aansluitingen voor naar de motor.

### Noodstop → Arduino
- Normaal gesloten knop tussen pin 5 en GND
- Ingedrukt = circuit open = motor stopt

### Dode man schakelaar → Arduino
- Normaal open knop tussen pin 6 en GND
- Vasthouden = circuit gesloten = motor draait
- Loslaten = circuit open = motor stopt direct

### RS485-bordje → Gele motorconnector (X60)
| RS485-bordje | Connector |
|---|---|
| A (+) | A (+) |
| B (-) | B (-) |
| GND | GND |

### Motorconnector pinout
- **A (+)** — RS485 Data+
- **B (-)** — RS485 Data-
- **GND** — Massa (2 pinnen)
- **VCC** — Motorvoeding van accu
- **NC** — Not connected

Bron: https://ardupilot.org/rover/_images/torqeedo-motor-cable-small-annotated.jpg

---

## Protocol (TQBus RS485)

- **Baud rate:** 19200
- **Header:** 0xAC
- **Footer:** 0xAD
- **Escape byte:** 0xAE (gevolgd door originele byte XOR 0x80)
- **CRC:** Dallas/Maxim CRC-8 (polynoom 0x8C)
- **Update interval:** 100ms (10Hz)

### Motoradres en commando
| Constante | Waarde |
|---|---|
| Adres MOTOR | 0x30 |
| Message ID DRIVE | 0x82 |

### DRIVE bericht payload (6 bytes)
| Byte | Inhoud |
|---|---|
| 0 | Adres: 0x30 (MOTOR) |
| 1 | Message ID: 0x82 (DRIVE) |
| 2 | Flags: 0x01 (enable, bit 0) |
| 3 | Motorvermogen: 0–100 |
| 4 | Snelheid hoog byte (signed, -1000 tot +1000) |
| 5 | Snelheid laag byte |

Gevolgd door CRC-byte, alles tussen 0xAC en 0xAD.

---

## Bediening — opties voor potmeter

| Optie | Voordeel | Nadeel | Codewijziging |
|---|---|---|---|
| IP67 potmeter | Zelfde aansluiting, waterdicht | Mechanisch contact slijt | Geen |
| Hall sensor (AS5600) | Geen mechanisch contact, onverwoestbaar | Iets meer software | Minimaal |
| IP67 joystick | Voor/achteruit in één beweging | Iets duurder | Kleine aanpassing |
| Marine gashendel | Professioneel, goede haptiek | Duurder | Kleine aanpassing |

**Aanbeveling nu:** IP67 potmeter — zelfde aansluiting als huidige potmeter, gewoon buiten het kastje monteren.

**Aanbeveling later:** marine gashendel voor een nette eindoplossing.

Zoektermen:
- IP67 potmeter: "IP67 potentiometer" of "waterproof potentiometer" (€5-15)
- Hall sensor: "AS5600 rotary encoder"
- Marine gashendel: "marine throttle control single lever"

---

## Robuustheid

| Maatregel | Implementatie |
|---|---|
| Noodstop | Normaal gesloten knop op pin 5 — indrukken stopt motor direct |
| Dode man schakelaar | Normaal open knop op pin 6 — loslaten stopt motor direct |
| Watchdog timer | Arduino herstart zichzelf als de code vastloopt (timeout 2 seconden) |
| Zachte start/stop | Snelheid verandert max 10 eenheden per 100ms (100 eenheden/sec) |
| Foutlogging | Aantal stops wordt opgeslagen in EEPROM, zichtbaar na herstart via Serial Monitor |
| Hardware (nog te doen) | Weg van breadboard (solderen/perfboard), getwiste RS485-paar, zekeringen (~40A motor / ~1A logica), buck-converter i.p.v. USB, hoofdschakelaar, waterproof behuizing |

---

## Arduino sketch

De volledige sketch staat in [`Torqeedo_motor/Torqeedo_motor.ino`](../Torqeedo_motor/Torqeedo_motor.ino).

---

## Testen

1. Sluit de potmeter aan op de Arduino (5V, GND, wiper naar A0)
2. Sluit het RS485-bordje aan op de Arduino (pin 2, 3, 4, 5V, GND)
3. Verbind RS485-bordje met de motorconnector (A+, B-, GND)
4. Zet de motorvoeding aan (24V accu)
5. Draai de potmeter — de motor zou moeten reageren

### Uitgevoerde banktest (2026-07-25) — geslaagd ✅

Getest tegen een echte Travel 1103 CL, onbelast (schroef in de lucht):

- Motorvoeding: regelbare DC-voeding (BaseTech BT-305) op **29V, 5A-limiet**.
  Logica (Arduino + RS485-bordje) apart gevoed via USB — met **gemeenschappelijke
  massa** tussen USB-GND en de min van de DC-voeding.
- Bij inschakelen trok de motorcontroller een **ruststroom van ~0,06A** (bewijs
  dat de motorelektronica opstartte en op commando's wachtte).
- Potmeter vooruit → schroef draaide vooruit; andere kant → schroef draaide
  **achteruit**. Aansturing en protocol werken dus.

**Nog niet getest:** gebruik onder belasting (in het water) en de definitieve
voedingsopbouw (buck-converter, zekeringen, hoofdschakelaar). Een DC-voeding van
5A is te zwak voor de motor onder belasting (~30A vol) — die is alleen geschikt
voor deze onbelaste banktest.

### Bekende valkuilen uit de banktest

| Symptoom | Oorzaak / oplossing |
|---|---|
| `Pot: 0`, `Target: -1000` blijft hangen | 5V-kant van de potmeter kwam niet aan (los draadje / dode railhelft). Meet 5V tussen de twee buitenpennen van de pot. |
| Alleen TXD-lampje knippert, RXD donker | Normaal zolang de motor niet aangesloten/antwoordend is: TXD = Arduino zendt, RXD licht pas op als de motor terugpraat. |
| Motor reageert niet | `A`/`B` omwisselen; gemeenschappelijke massa ontbreekt; DE niet geschakeld. |
| Breadboard-voeding valt steeds weg | Massief draad i.p.v. gevlochten, verse gaatjes, beide railhelften voeden. Breadboard is sowieso ongeschikt voor de eindopstelling (trillingen). |

---

## Behuizing

> Voor de volledige waterdichte én trillingsbestendige eindopbouw (weg van het
> breadboard), zie [`ip68-robuuste-opbouw.md`](ip68-robuuste-opbouw.md). Hieronder
> een korte samenvatting.

**Type:** IP67 of IP68 afdichtingsbox (spatwaterdicht tot onderwaterdicht)

**Formaat:** minimaal 15×10×6cm (Arduino Uno is 68×53mm)

**Materiaal:** ABS kunststof (goedkoop, voldoende) of aluminium (robuuster)

**Kabeldoorvoeren:** blindnippels of PG-kabelwartels voor draden naar buiten (motor, potmeter, knoppen, voeding)

### Waar te koop

| Winkel | Zoekterm |
|---|---|
| Gamma / Praxis | afdichtdoos buitengebruik (IP65/IP67, €5-10) |
| Conrad | "IP67 behuizing" of "afdichtdoos" |
| Kiwi Electronics | "waterproof enclosure" |
| Reichelt | "Gehäuse IP67" |
| Amazon | "IP67 junction box ABS" |

Voor een prototype volstaat een Gamma/Praxis afdichtdoos. Voor een nettere uitvoering: aluminium Hammond-behuizing via Conrad of Reichelt.

### Kabeldoorvoeren

Kabels komen waterdicht naar buiten via **PG-kabelwartels**:

1. Boor een gat in de zijkant van het kastje
2. Schroef de kabelwartel erin (met moer aan de binnenkant)
3. Voer de kabel erdoor
4. Draai de kap aan — die knijpt een rubberen ring om de kabel dicht

**Maten:** PG7 (dunne draadjes) of PG9 (iets dikker)

**Benodigde wartels:**

| Wartel | Voor |
|---|---|
| 1× | Motorcabel (RS485 A/B/GND) |
| 1× | Potmeterkabel |
| 1× | Noodstop + dode man knoppen |
| 1× | Voedingskabel |

**Waar te koop:** Conrad, Gamma, Praxis — €0,50-2,00 per stuk.

---

## Voedingsplan

- **Nu:** 24V LiFePO4 accu (originele Torqeedo batterij, ~29V vol)
- **Later:** 48V accu → Victron Orion DC-DC converter → 24V naar motor

### Voeding elektronica

Alles loopt op 5V uit de Arduino. De Arduino krijgt voeding van een **step-down converter** (buck converter) aangesloten op de 24V accu.

```
24V accu ──→ Step-down converter (24V → 5V) ──→ Arduino VIN of 5V pin
                                                        │
                                                        ├──→ TTL-RS485 bordje (via 5V pin)
                                                        └──→ Potmeter (via 5V pin)
```

Knoppen (noodstop, dode man) hebben geen eigen voeding nodig — die lopen via de Arduino.

**Instellen:** stel de step-down converter in op **5V uitgang** voordat je hem aansluit op de Arduino. Te hoog voltage beschadigt de Arduino.

**Aansluiting step-down → Arduino:**
- Uitgang + → Arduino VIN (als de converter regelbaar is en je zeker bent van 7-12V) of rechtstreeks naar 5V pin (als de converter exact op 5V staat)
- Uitgang − → Arduino GND

**Extra wartel nodig:** voedingskabel van accu naar kastje via PG-kabelwartel.

---

## Bronnen

- ArduPilot AP_Torqeedo library: https://github.com/ArduPilot/ardupilot/tree/master/libraries/AP_Torqeedo
- ArduPilot Torqeedo documentatie: https://ardupilot.org/rover/docs/common-torqeedo.html
- Connector pinout afbeelding: https://ardupilot.org/rover/_images/torqeedo-motor-cable-small-annotated.jpg

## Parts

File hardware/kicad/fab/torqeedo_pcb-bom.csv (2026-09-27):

Ref | Waarde | Footprint | Aantal
C1 | 100uF/25V | Capacitor_THT:CP_Radial_D6.3mm_P2.50mm | 1
C2,C12 | 10uF | Capacitor_SMD:C_0805_2012Metric | 2
C3-C6,C9-C11,C13 | 100nF | Capacitor_SMD:C_0805_2012Metric | 8
C7,C8 | 22pF | Capacitor_SMD:C_0805_2012Metric | 2
D1 | SS34 | Diode_SMD:D_SMA | 1
JP_BA? | bias A | Connector_PinHeader_2.54mm:PinHeader_1x02_P2.54mm_Vertical | 1
JP_BB? | bias B | Connector_PinHeader_2.54mm:PinHeader_1x02_P2.54mm_Vertical | 1
JP_TERM? | 120R term | Connector_PinHeader_2.54mm:PinHeader_1x02_P2.54mm_Vertical | 1
J_DMAN? | Dode man NO | Connector_PinHeader_2.54mm:PinHeader_1x02_P2.54mm_Vertical | 1
J_ESTOP? | Noodstop NC | Connector_PinHeader_2.54mm:PinHeader_1x02_P2.54mm_Vertical | 1
J_FTDI? | FTDI | Connector_PinHeader_2.54mm:PinHeader_1x06_P2.54mm_Vertical | 1
J_ISP? | ISP | Connector_PinHeader_2.54mm:PinHeader_2x03_P2.54mm_Vertical | 1
J_POT? | Potmeter | Connector_PinHeader_2.54mm:PinHeader_1x03_P2.54mm_Vertical | 1
J_PWR? | +12V in | TerminalBlock:TerminalBlock_bornier-2_P5.08mm | 1
J_RS485 | RS485 bus | TerminalBlock:TerminalBlock_bornier-3_P5.08mm | 1
L1 | 10uH | Inductor_SMD:L_1210_3225Metric | 1
PS1 | Buck 12V->5V | Connector_PinHeader_2.54mm:PinHeader_1x04_P2.54mm_Vertical | 1
R1 | 120 | Resistor_SMD:R_0805_2012Metric | 1
R2,R3 | 560 | Resistor_SMD:R_0805_2012Metric | 2
R4,R5,R8 | 10k | Resistor_SMD:R_0805_2012Metric | 3
R6,R7 | 100k | Resistor_SMD:R_0805_2012Metric | 2
SW1 | Reset | Button_Switch_THT:SW_PUSH_6mm | 1
TVS1 | SM712 | Package_TO_SOT_SMD:SOT-23 | 1
U1 | MAX485 | Package_SO:SOIC-8_3.9x4.9mm_P1.27mm | 1
U2 | ATmega328P-PU | Package_DIP:DIP-28_W7.62mm | 1
Y1 | 16MHz | Crystal:Crystal_HC49-U_Vertical | 1

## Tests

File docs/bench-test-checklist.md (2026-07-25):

# Bench-test checklist — Torqeedo motoraansturing

Doorloop deze lijst **op de werkbank**, vóór elk gebruik op het water. Test in de
volgorde hieronder: eerst alles zonder motorvoeding, daarna pas met de accu erop
en **altijd zonder belasting** (schroef eraf of boot vastgezet).

> ✅ De sketch is **gevalideerd tegen de echte motor** (banktest 2026-07-25,
> onbelast, schroef in de lucht — vooruit én achteruit werkend). De aansturing
> en het RS485-protocol kloppen dus. Wat nog **niet** is getest: gebruik onder
> belasting en de definitieve voedingsopbouw (buck, zekeringen, hoofdschakelaar).
> Blijf extra voorzichtig: houd je hand bij de noodstop en de hoofdschakelaar.

---

## 0. Vooraf

- [ ] Schroef verwijderd, of boot stevig vastgezet zodat er geen stuwkracht kan ontstaan
- [ ] Hoofdschakelaar / uittrekstekker UIT, accu losgekoppeld
- [ ] Laatste `Torqeedo_motor/Torqeedo_motor.ino` geüpload (board **Arduino Uno**, upload zonder fouten)
- [ ] Brandblusser / manier om snel de stroom eraf te halen binnen handbereik

## 1. Bedrading controleren (visueel, stroomloos)

- [ ] `2` → MAX485 `DI`, `3` → `RO`, `4` → `DE`+`RE` (samen)
- [ ] MAX485 `VCC` → 5V, `GND` → GND
- [ ] Potmeter: wiper → `A0`, buitenpennen → 5V en GND
- [ ] Noodstop (normaal gesloten) tussen pin `5` en GND
- [ ] Dode man (normaal open) tussen pin `6` en GND
- [ ] RS485 `A`/`B` naar de motorconnector (polariteit later verifiëren)
- [ ] **Gemeenschappelijke massa**: accu-, Arduino- en MAX485-GND aan elkaar
- [ ] Twee aparte zekeringen: zwaar (~40A) motorcircuit, klein (~1A) logica

## 2. Eerste keer aan — alleen logica, GEEN motorvoeding

Voed alleen de Arduino (USB of buck), motoraccu nog LOS.

- [ ] Serial Monitor open op **9600 baud**
- [ ] Bij opstarten verschijnt `Stored errors: <n>` en daarna `Start`
- [ ] Loop print continu `Pot: … Target: … Current: …`
- [ ] Potmeter op **midden** → `Target` ≈ 0 (binnen de dode zone)
- [ ] Potmeter naar één kant → `Target` loopt naar **+1000** (vooruit)
- [ ] Potmeter naar de andere kant → `Target` loopt naar **−1000** (achteruit)
- [ ] `Current` volgt `Target` **geleidelijk** (soft-start, max ~10 per stap)
- [ ] Dode zone werkt: kleine afwijking rond het midden → `Target` blijft 0

## 3. Veiligheidsschakelaars (nog steeds zonder motorvoeding)

- [ ] Noodstop indrukken → `STOP: emergency stop` verschijnt **één keer**, `Current` → 0
- [ ] Noodstop ingedrukt houden → géén herhaalde STOP-regels (edge-logging werkt)
- [ ] Noodstop loslaten → loop draait weer normaal
- [ ] Dode man **loslaten** → `STOP: dead man switch`, `Current` → 0
- [ ] Dode man vasthouden → loop draait normaal
- [ ] Bij een STOP loopt `Stored errors` bij herstart met precies +1 per gebeurtenis

## 4. Watchdog

- [ ] (Optioneel) simuleer een hang: tijdelijk een `while(1);` inbouwen →
      Arduino herstart binnen ~2 s (je ziet opnieuw `Start`). **Fix daarna terugdraaien!**

## 5. Met motorvoeding — zonder belasting

Sluit nu pas de motoraccu aan. Schroef eraf / boot vast. Hand bij de noodstop.

- [ ] Buck-converter meet **5V** aan de Arduino (vóór aansluiten gecontroleerd)
- [ ] Motoraccu-spanning plausibel (~24–29V)
- [ ] Potmeter op midden bij inschakelen → motor blijft **stil**
- [ ] Langzaam vooruit → motor draait vooruit, toerental volgt de potmeter
- [ ] Reageert de motor niet? Zet dan `A`/`B` op de RS485-bus om
- [ ] Langzaam achteruit → motor draait de **andere** kant op
- [ ] Door het midden bewegen (vooruit↔achteruit) → gaat vloeiend via nul
- [ ] **Noodstop onder belastingloos toerental** → motor stopt direct
- [ ] **Dode man loslaten onder toerental** → motor stopt direct
- [ ] Hoofdschakelaar / uittrekstekker → hele systeem valt dood (onafhankelijk van software)

## 6. Afronden

- [ ] Geen oververhitting bij MAX485, buck-converter of bedrading (voel/ruik)
- [ ] `Stored errors`-teller genoteerd (nulpunt voor volgende sessie)
- [ ] Pas ná een volledig geslaagde banktest: overweeg een test met schroef in het
      water, aangemeerd en met iemand aan de noodstop

---

## Faalgedrag — wat te doen

| Symptoom | Waarschijnlijke oorzaak |
|---|---|
| Motor reageert niet | `A`/`B` omgedraaid, geen gemeenschappelijke massa, DE niet geschakeld |
| Motor kruipt bij neutraal | Potmeter niet op midden, of dode zone te klein |
| Draait verkeerde kant op | Potmeter-buitenpennen omdraaien, of `A`/`B` |
| Continue STOP-regels | Schakelaarlogica omgekeerd (NC/NO) — controleer bedrading pin 5/6 |
| Willekeurige herstarts | Watchdog trigger (loop te traag) of voedingsdip op de 5V |

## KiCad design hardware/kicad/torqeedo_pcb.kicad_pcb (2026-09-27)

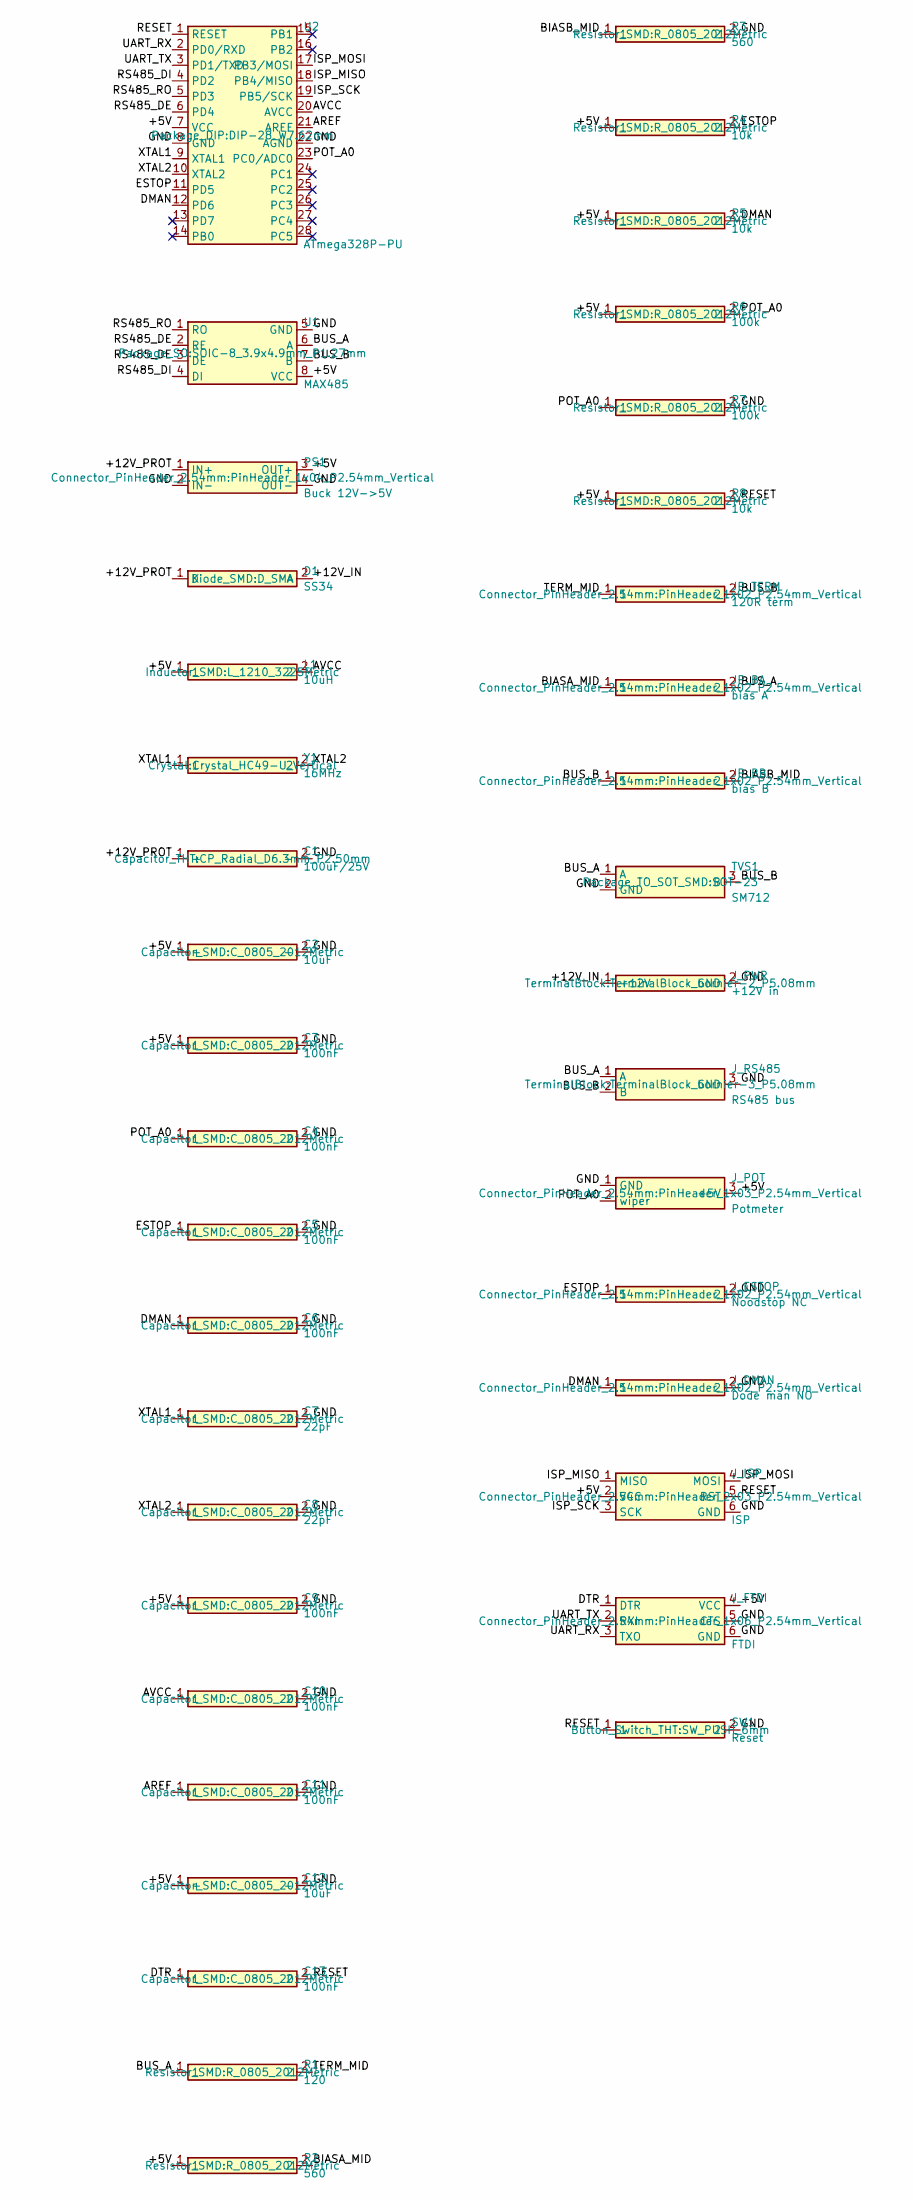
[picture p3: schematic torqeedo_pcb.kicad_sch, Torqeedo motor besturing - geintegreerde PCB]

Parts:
C1: 100uF/25V; CP_Radial_D6.3mm_P2.50mm
C2, C12: 10uF; C_0805_2012Metric
C3, C4, C5, C6, C9, C10, C11, C13: 100nF; C_0805_2012Metric
C7, C8: 22pF; C_0805_2012Metric
D1: SS34; D_SMA
JP_BA: bias A; PinHeader_1x02_P2.54mm_Vertical
JP_BB: bias B; PinHeader_1x02_P2.54mm_Vertical
JP_TERM: 120R term; PinHeader_1x02_P2.54mm_Vertical
J_DMAN: Dode man NO; PinHeader_1x02_P2.54mm_Vertical
J_ESTOP: Noodstop NC; PinHeader_1x02_P2.54mm_Vertical
J_FTDI: FTDI; PinHeader_1x06_P2.54mm_Vertical
J_ISP: ISP; PinHeader_2x03_P2.54mm_Vertical
J_POT: Potmeter; PinHeader_1x03_P2.54mm_Vertical
J_PWR: +12V in; TerminalBlock_bornier-2_P5.08mm
J_RS485: RS485 bus; TerminalBlock_bornier-3_P5.08mm
L1: 10uH; L_1210_3225Metric
PS1: Buck 12V->5V; PinHeader_1x04_P2.54mm_Vertical
R1: 120; R_0805_2012Metric
R2, R3: 560; R_0805_2012Metric
R4, R5, R8: 10k; R_0805_2012Metric
R6, R7: 100k; R_0805_2012Metric
SW1: Reset; SW_PUSH_6mm
TVS1: SM712; SOT-23
U1: MAX485; SOIC-8_3.9x4.9mm_P1.27mm
U2: ATmega328P-PU; DIP-28_W7.62mm
Y1: 16MHz; Crystal_HC49-U_Vertical

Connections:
/+5V: C2.1 (+), C3.1, C9.1, C12.1 (+), J_FTDI.4 (VCC), J_ISP.2 (VCC), J_POT.3 (+5V), L1.1, PS1.3 (OUT+), R2.1, R4.1, R5.1, R6.1, R8.1, U1.8 (VCC), U2.7 (VCC)
/+12V_IN: D1.2 (A), J_PWR.1 (+12V)
/+12V_PROT: C1.1 (+), D1.1 (K), PS1.1 (IN+)
/AREF: C11.1, U2.21 (AREF)
/AVCC: C10.1, L1.2, U2.20 (AVCC)
/BIASA_MID: JP_BA.1, R2.2
/BIASB_MID: JP_BB.2, R3.1
/BUS_A: JP_BA.2, J_RS485.1 (A), R1.1, TVS1.1 (A), U1.6 (A)
/BUS_B: JP_BB.1, JP_TERM.2, J_RS485.2 (B), TVS1.3 (B), U1.7 (B)
/DMAN: C6.1, J_DMAN.1, R5.2, U2.12 (PD6)
/DTR: C13.1, J_FTDI.1 (DTR)
/ESTOP: C5.1, J_ESTOP.1, R4.2, U2.11 (PD5)
/GND: C1.2 (-), C2.2 (-), C3.2, C4.2, C5.2, C6.2, C7.2, C8.2, C9.2, C10.2, C11.2, C12.2 (-), J_DMAN.2, J_ESTOP.2, J_FTDI.5 (CTS), J_FTDI.6 (GND), J_ISP.6 (GND), J_POT.1 (GND), J_PWR.2 (GND), J_RS485.3 (GND), PS1.2 (IN-), PS1.4 (OUT-), R3.2, R7.2, SW1.2, TVS1.2 (GND), U1.5 (GND), U2.8 (GND), U2.22 (AGND)
/ISP_MISO: J_ISP.1 (MISO), U2.18 (PB4/MISO)
/ISP_MOSI: J_ISP.4 (MOSI), U2.17 (PB3/MOSI)
/ISP_SCK: J_ISP.3 (SCK), U2.19 (PB5/SCK)
/POT_A0: C4.1, J_POT.2 (wiper), R6.2, R7.1, U2.23 (PC0/ADC0)
/RESET: C13.2, J_ISP.5 (RST), R8.2, SW1.1, U2.1 (RESET)
/RS485_DE: U1.2 (RE), U1.3 (DE), U2.6 (PD4)
/RS485_DI: U1.4 (DI), U2.4 (PD2)
/RS485_RO: U1.1 (RO), U2.5 (PD3)
/TERM_MID: JP_TERM.1, R1.2
/UART_RX: J_FTDI.3 (TXO), U2.2 (PD0/RXD)
/UART_TX: J_FTDI.2 (RXI), U2.3 (PD1/TXD)
/XTAL1: C7.1, U2.9 (XTAL1), Y1.1
/XTAL2: C8.1, U2.10 (XTAL2), Y1.2

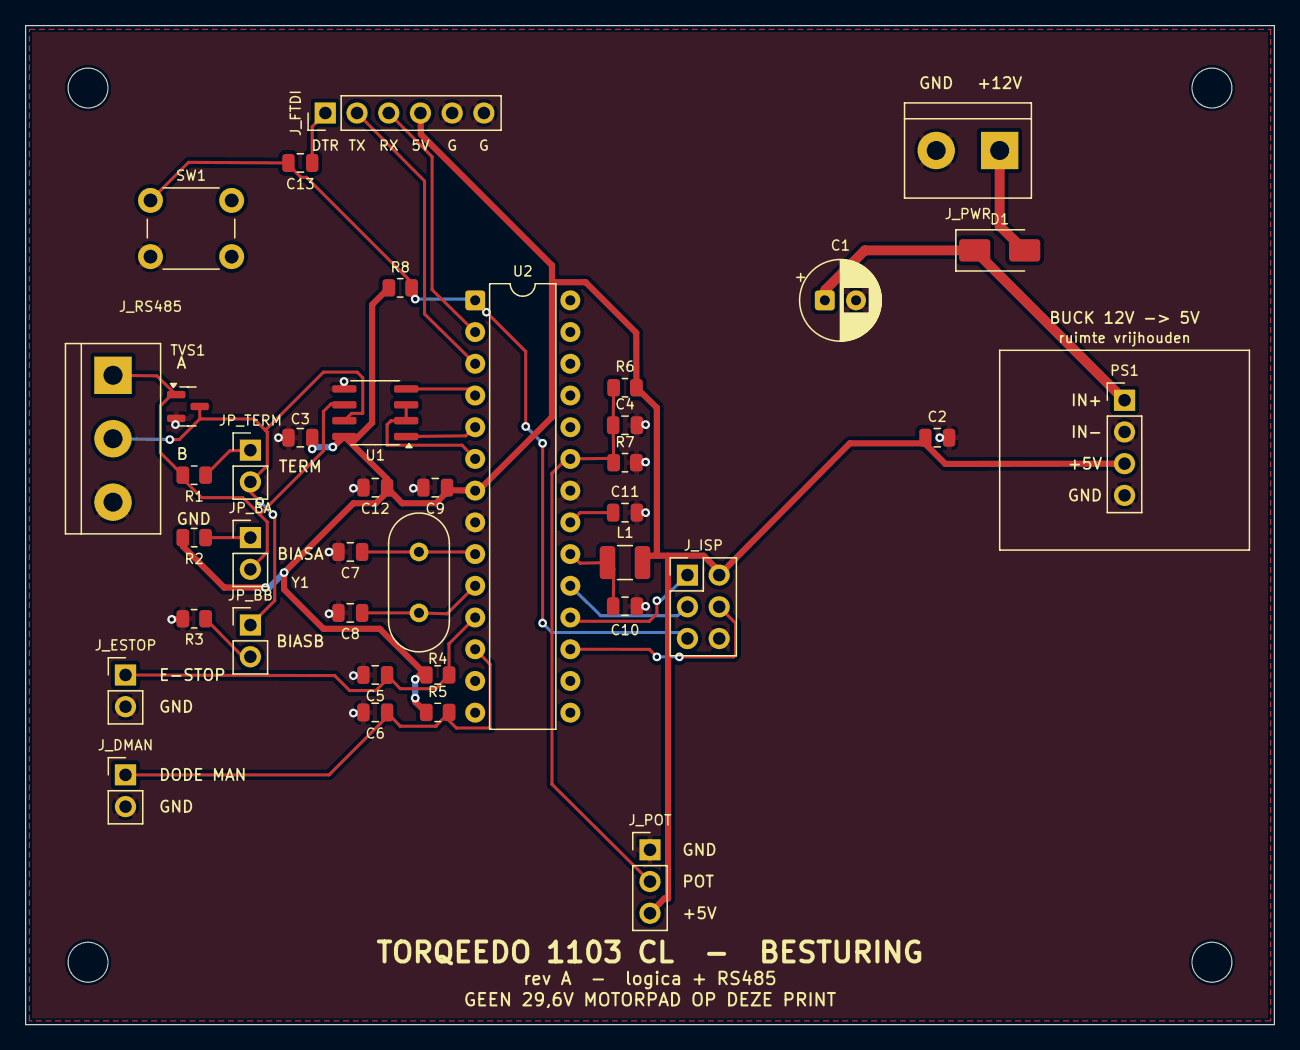
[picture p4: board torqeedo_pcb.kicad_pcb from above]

Board: 2 copper layers, 100.0 x 80.0 mm, 43 parts (0 on the bottom side), 26 nets.

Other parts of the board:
H1, H2, H3, H4: (no value)

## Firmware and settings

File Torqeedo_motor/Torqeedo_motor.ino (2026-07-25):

// Copyright (C) 2026 antoinem01
//
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
// Torqeedo RS485 bus protocol (framing bytes 0xAC/0xAD/0xAE, CRC8) is based on
// ArduPilot's AP_Torqeedo driver: https://github.com/ArduPilot/ardupilot
// (libraries/AP_Torqeedo), licensed under the GNU GPLv3. See LICENSE.

#include <SoftwareSerial.h>
#include <avr/wdt.h>
#include <EEPROM.h>

#define RS485_TX      2
#define RS485_RX      3
#define RS485_DE      4
#define POT_PIN       A0
#define NOODSTOP_PIN  5   // normally closed button between pin and GND
#define DODE_MAN_PIN  6   // normally open button between pin and GND

#define EEPROM_FOUTEN 0   // EEPROM address for error counter

#define COMMS_TIMEOUT_MS 1000  // fail-safe stop if no valid motor reply for this
                               // long (only enforced once comms has been seen)

SoftwareSerial rs485(RS485_RX, RS485_TX);

int16_t huidigSnelheid = 0;
uint8_t foutTeller = 0;
bool gestopt = false;   // true while a safety switch keeps the motor stopped

unsigned long laatsteReplyMs = 0;  // millis() of the last valid motor reply
bool commsGezien = false;          // true once the motor has ever replied validly
bool commsVerloren = false;        // edge flag: comms-loss already logged this event

uint8_t crc8(uint8_t *data, uint8_t len) {
  uint8_t crc = 0;
  for (uint8_t i = 0; i < len; i++) {
    uint8_t b = data[i];
    for (uint8_t j = 0; j < 8; j++) {
      uint8_t mix = (crc ^ b) & 0x01;
      crc >>= 1;
      if (mix) crc ^= 0x8C;
      b >>= 1;
    }
  }
  return crc;
}

void schrijfByte(uint8_t b) {
  if (b == 0xAC || b == 0xAD || b == 0xAE) {
    rs485.write(0xAE);
    rs485.write(b ^ 0x80);
  } else {
    rs485.write(b);
  }
}

void stuurSnelheid(int16_t snelheid) {
  // Assert the enable flag only when actually commanding motion, matching
  // ArduPilot's safe/neutral state. At zero speed the motor is disabled
  // (flags 0, power 0), so a stop is a true motor-disable instead of "enabled
  // at speed zero". Every safety stop (emergency stop, dead man, comms loss)
  // routes through stuurSnelheid(0), so they all land in this disabled state.
  uint8_t vermogen = map(abs(snelheid), 0, 1000, 0, 100);
  uint8_t flags = (snelheid != 0) ? 0x01 : 0x00;  // 0x01 = enable motor
  uint8_t payload[6] = {
    0x30,                        // address: MOTOR
    0x82,                        // message ID: DRIVE
    flags,                       // flags: enable only when moving
    vermogen,                    // motor power 0-100
    (uint8_t)(snelheid >> 8),    // speed high byte
    (uint8_t)(snelheid & 0xFF)   // speed low byte
  };
  uint8_t crc = crc8(payload, 6);
  digitalWrite(RS485_DE, HIGH);
  rs485.write(0xAC);
  for (int i = 0; i < 6; i++) schrijfByte(payload[i]);
  schrijfByte(crc);
  rs485.write(0xAD);
  digitalWrite(RS485_DE, LOW);
}

// Drain the RS485 receive buffer and reassemble any reply frame the motor sent
// (same framing as we transmit: 0xAC start, 0xAD end, 0xAE escape + XOR 0x80,
// trailing CRC8). Returns true if at least one complete, CRC-valid frame was
// decoded. We only need "did the motor answer?", not the payload contents, so
// a valid frame is enough to prove the bus and controller are alive. Parser
// state is static so a frame split across calls is still reassembled.
bool leesMotorReply() {
  static uint8_t buf[32];
  static uint8_t len = 0;
  static bool inFrame = false;
  static bool escape = false;
  bool geldig = false;

  while (rs485.available()) {
    uint8_t b = rs485.read();
    if (b == 0xAC) {            // start of frame (resync on any 0xAC)
      inFrame = true; escape = false; len = 0;
      continue;
    }
    if (!inFrame) continue;     // junk before a start byte
    if (b == 0xAD) {            // end of frame: last byte is the CRC
      inFrame = false;
      if (len >= 2 && crc8(buf, len - 1) == buf[len - 1]) geldig = true;
      continue;
    }
    if (b == 0xAE) { escape = true; continue; }  // next byte is XOR 0x80
    if (escape) { b ^= 0x80; escape = false; }
    if (len < sizeof(buf)) buf[len++] = b;
    else inFrame = false;       // overflow: drop this frame
  }
  return geldig;
}

// Keep the motor stopped. Logs the stop and bumps the EEPROM error counter only
// once, on the transition into the stopped state, to avoid wearing out the EEPROM
// while a switch is held (the loop runs every ~100 ms).
void motorStop(const char* reden) {
  huidigSnelheid = 0;
  stuurSnelheid(0);
  if (!gestopt) {
    Serial.print("STOP: ");
    Serial.println(reden);
    if (foutTeller < 255) foutTeller++;
    EEPROM.update(EEPROM_FOUTEN, foutTeller);
    gestopt = true;
  }
}

void setup() {
  // Clear the reset flags and disable any watchdog carried over from a prior
  // reset. Without this, a watchdog (or brown-out) reset can leave the WDT
  // enabled with a short timeout, so the board resets again before setup()
  // finishes — an endless bootloop. Must run before anything else.
  MCUSR = 0;
  wdt_disable();

  Serial.begin(9600);

  pinMode(RS485_DE, OUTPUT);
  digitalWrite(RS485_DE, LOW);
  pinMode(NOODSTOP_PIN, INPUT_PULLUP);
  pinMode(DODE_MAN_PIN, INPUT_PULLUP);

  rs485.begin(19200);

  foutTeller = EEPROM.read(EEPROM_FOUTEN);
  Serial.print("Stored errors: ");
  Serial.println(foutTeller);

  laatsteReplyMs = millis();  // arm the comms clock; fail-safe stays dormant
                              // until the motor has actually replied once

  wdt_enable(WDTO_2S);  // restart Arduino if the loop hangs
  Serial.println("Start");
}

void loop() {
  wdt_reset();  // tell the watchdog everything is OK

  // Read any reply the motor sent since our last frame. A valid framed reply
  // proves the RS485 link and the motor controller are alive.
  if (leesMotorReply()) {
    laatsteReplyMs = millis();
    if (!commsGezien) {
      Serial.println("Motor comms OK");  // fail-safe is now armed
      commsGezien = true;
    }
    commsVerloren = false;
  }

  // Emergency stop (normally closed: LOW = OK, HIGH = pressed = stop)
  if (digitalRead(NOODSTOP_PIN) == HIGH) {
    motorStop("emergency stop");
    delay(100);
    return;
  }

  // Dead man switch (normally open button to GND, INPUT_PULLUP):
  // held = closed = LOW = run, released = open = HIGH = stop. A broken or
  // disconnected wire reads HIGH too, so it fails safe to stop.
  if (digitalRead(DODE_MAN_PIN) == HIGH) {
    motorStop("dead man switch");
    delay(100);
    return;
  }

  // Both safety switches OK again: allow the next stop to be logged.
  gestopt = false;

  // Comms-loss fail-safe: once the motor has ever replied, a prolonged silence
  // means a broken bus or a dead controller. Command stop and refuse to drive
  // until replies resume, so we never keep pushing a link we've lost. If the
  // motor never replies (commsGezien stays false) this stays dormant, so it
  // can't brick a setup where the motor sends no status back.
  if (commsGezien && (millis() - laatsteReplyMs) > COMMS_TIMEOUT_MS) {
    huidigSnelheid = 0;
    stuurSnelheid(0);
    if (!commsVerloren) {
      Serial.println("STOP: comms lost");
      if (foutTeller < 255) foutTeller++;
      EEPROM.update(EEPROM_FOUTEN, foutTeller);
      commsVerloren = true;
    }
    delay(100);
    return;
  }

  // Read potentiometer and convert. Centre = stop: fully left = full reverse,
  // middle = idle, fully right = full forward.
  int pot = analogRead(POT_PIN);
  int16_t doelSnelheid = map(pot, 0, 1023, -1000, 1000);

  // Dead zone around the centre so the motor doesn't creep at neutral (a pot
  // rarely sits exactly at the middle).
  if (abs(doelSnelheid) < 50) doelSnelheid = 0;

  // Soft start/stop: max 10 units per step (100ms = max 100 units/sec)
  if (doelSnelheid > huidigSnelheid + 10)      huidigSnelheid += 10;
  else if (doelSnelheid < huidigSnelheid - 10) huidigSnelheid -= 10;
  else                                          huidigSnelheid = doelSnelheid;

  Serial.print("Pot: ");      Serial.print(pot);
  Serial.print("  Target: "); Serial.print(doelSnelheid);
  Serial.print("  Current: "); Serial.println(huidigSnelheid);

  stuurSnelheid(huidigSnelheid);
  delay(100);
}

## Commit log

2026-07-16 Initial commit: Torqeedo motor control sketch
2026-07-16 Relicense as GPLv3 and credit ArduPilot's AP_Torqeedo driver
    The RS485 protocol implementation is based on ArduPilot's AP_Torqeedo
    driver, which is GPLv3-licensed. Switching from MIT to GPLv3 to comply
    with that license, and adding attribution in the README and sketch.
2026-07-16 Fix swapped RS485 TX/RX pin numbers in README
2026-07-16 Document RS485/MAX485 wiring, safety notes and untested-motor status
2026-07-16 Note target motor model: Torqeedo Travel 1103 CL
2026-07-16 Add system diagram for the intended full setup
    Covers battery/BMS, fuses, main switch, buck converter, Uno, and
    TTL-RS485 module, with notes on separate fusing and common ground.
2026-07-16 Split Hardware section into explicit components and pins lists
    The MAX485 module and motor weren't listed as components before,
    only implied through pin descriptions.
2026-07-24 Log/write EEPROM only on transition into stopped state
    motorStop() ran every ~100 ms loop while a safety switch was held,
    writing the EEPROM error counter each time. Holding the emergency stop
    or releasing the dead man switch produced ~10 EEPROM writes/second,
    wearing out the counter cell within hours.
    Track a `gestopt` flag and only log + bump the counter on the edge into
    the stopped state, using EEPROM.update() and guarding against uint8_t
    wrap. The motor is still commanded to 0 every loop, so safety behaviour
    is unchanged. Reset the flag once both switches are OK again.
    Also replace the duplicated sketch code block in the docs with a link to
    Torqeedo_motor.ino to keep a single source of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
    [Torqeedo_motor.ino]
2026-07-24 Add reverse and a neutral dead zone to the pot mapping
    Map the potentiometer to -1000..+1000 (centre = stop) so the motor can
    run in reverse as well as forward. The DRIVE protocol and stuurSnelheid()
    already handle signed speed and use abs() for power, so only the input
    mapping needed to change.
    Add a ~5% dead zone around the centre so the motor doesn't creep at
    neutral, since a pot rarely sits exactly in the middle. Update the docs
    to describe the centre-is-stop operation.
    Claude-Session: https://claude.ai/code/session_01C4aChePtANqkDftMbK3e3e
    [Torqeedo_motor.ino]
2026-07-24 Add bench-test checklist
    Document a safe, ordered bench-test procedure to run before any on-water
    use: wiring checks, logic-only power-on (verifying forward/reverse and the
    neutral dead zone via the serial output), the safety switches (including
    the single-log edge behaviour and the EEPROM counter), the watchdog, and
    finally motor-powered no-load tests. Includes a failure-mode table.
    Link it from the README docs section.
    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
2026-07-24 Fix inverted dead man switch logic; adopt Arduino sketch-folder layout
    The dead man switch is a normally-open button to GND with INPUT_PULLUP:
    held = closed = LOW = run, released = open = HIGH = stop (as the docs
    describe). The code stopped on LOW, so it stopped while held and ran when
    released — the opposite of a dead man switch, and not fail-safe: a broken
    or disconnected wire reads HIGH and must stop the motor. Change the test
    to stop on HIGH.
    Also move the sketch into a Torqeedo_motor/ subfolder so it matches the
    Arduino IDE's required sketch-folder layout (the IDE moves it there on
    open otherwise), and update the doc links to the new path.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
    [Torqeedo_motor.ino]
2026-07-25 Record successful bench validation against real 1103 CL motor
    The sketch was tested against an actual Torqeedo Travel 1103 CL on the
    bench (2026-07-25), powered from an adjustable DC supply at 29 V with the
    propeller in air (no load). The motor controller drew ~0.06 A idle and
    the propeller ran both forward and reverse on command, so the RS485
    protocol is validated against this model.
    - README: replace the "not yet tested" status with the validation
    result, noting it was no-load only and the robust power topology is
    still unbuilt.
    - bench-test checklist: flip the top warning from "not validated" to
    "validated (no-load), load and final power supply still untested".
    - aansturing doc: ad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
2026-07-25 Read motor replies and fail-safe on comms loss
    The drive loop was open-loop: it kept sending DRIVE frames and never
    looked at what the motor sent back, so a broken bus or dead controller
    went unnoticed.
    - Add leesMotorReply(): drains the RS485 RX buffer and reassembles reply
    frames (0xAC/0xAD framing, 0xAE escape, trailing CRC8), returning true
    on a complete CRC-valid frame. We only need "did the motor answer?",
    so framing + CRC is enough; the payload is not interpreted.
    - Track the time of the last valid reply. Once the motor has replied at
    least once (commsGezien), a silence longer than COMMS_TIMEOUT_MS (1 s)
    triggers a fail-safe: command speed 0, log "STOP: comms lost" once, an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
    [Torqeedo_motor.ino]
2026-07-25 Add IP68 & vibration-resistant build guide
    Document how to take the setup from a breadboard prototype to a
    waterproof (IP68), shock- and vibration-resistant unit fit for permanent
    use on a boat.
    - New docs/ip68-robuuste-opbouw.md: IP67 vs IP68 (what you actually
    need), sealed-enclosure vs full potting trade-offs, mounting the
    electronics off the breadboard (soldered, components secured, conformal
    coating), IP68 glands/M12 connectors, condensation & pressure-
    equalization breather, sealed control/e-stop/dead-man, cable routing,
    corrosion (A4/316 stainless), heat management for the buck converter,
    a water + vibration test protocol, a parts/search-term list and a
    checklist.
    - Lin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
2026-07-25 Clear reset flags and disable watchdog at start of setup()
    The sketch enables a 2 s watchdog but never cleared the reset flags or
    disabled a carried-over watchdog at startup. After a watchdog or brown-out
    reset the WDT can stay enabled with a short timeout, so the board resets
    again before setup() finishes — an endless bootloop. For a motor
    controller a controller stuck rebooting is a safety problem: it can't
    command a stop.
    Observed on the bench: after an avrdude-triggered reset the board looped,
    printing only the first two characters of the boot banner every ~2 s.
    Fix: clear MCUSR and call wdt_disable() as the very first thing in
    setup(), before re-arming the 2 s watchdog. Verified on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
    [Torqeedo_motor.ino]
2026-07-25 Only assert the enable flag when commanding motion
    The DRIVE frame always set the flags byte to 0x01 (enable), even at zero
    speed and during safety stops. ArduPilot's AP_Torqeedo driver instead
    clears the enable bit when speed is zero, so its neutral state is a true
    motor-disable rather than "enabled at speed zero".
    Match that: set flags to 0x01 only when speed != 0, else 0x00. Power
    already maps to 0 at zero speed. Because every safety stop (emergency
    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
2026-09-27 Add routed PCB layout for the integrated control board
    The KiCad schematic and docs/pcb-geintegreerd.md existed but were never
    committed, and there was no board file. This lands both, plus the layout.
    Schematic fix: J_PWR and J_RS485 referenced TerminalBlock_bornier-2/-3,
    which KiCad 9 renamed to *_P5.08mm, so both footprints were unresolvable.
    The board (torqeedo_pcb.kicad_pcb), 100 x 80 mm, 2 layers:
    - fully routed, 203 tracks and 32 vias; B.Cu left as a continuous ground
    plane (92.8% coverage, single island) with 15 stitching vias
    - placement follows docs/pcb-geintegreerd.md section 11: crystal hard
    against pins 9/10 (XTAL1 9.1 mm, XTAL2 10.0 mm, no vias), decoupling at
    the suppl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
    [torqeedo_pcb-B_Cu.gbr, torqeedo_pcb-B_Mask.gbr, torqeedo_pcb-B_Silkscreen.gbr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]

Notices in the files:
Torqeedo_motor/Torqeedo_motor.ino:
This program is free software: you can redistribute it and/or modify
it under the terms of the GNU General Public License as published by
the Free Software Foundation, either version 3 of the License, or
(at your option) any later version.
